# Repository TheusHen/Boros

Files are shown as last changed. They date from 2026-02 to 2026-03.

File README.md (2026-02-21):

# Boros Rocket

*Amateur rocket created by an 15 year old teenager.*

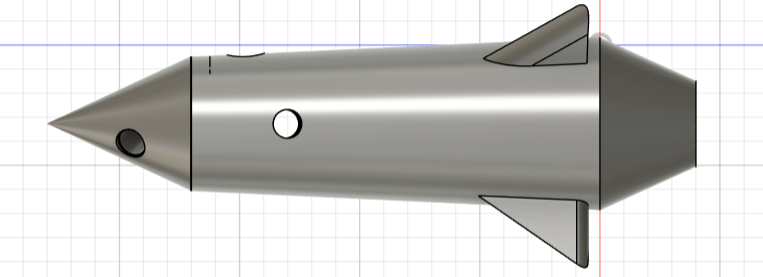
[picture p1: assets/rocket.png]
Boros Rocket


This repository contains the current **Beta** state of the Boros rocket avionics stack.  
The project has already passed **Pre-Alpha** and **Alpha** stages and is now focused on stabilizing hardware-software integration with the **Plate PCB version**.

## Current Focus

- Firmware flight logging and fault handling (`firmware/`)
- Physics-based flight simulation and Monte Carlo (`sim/flight/`)
- PCB design and manufacturing outputs (`PCB/plate_version/`)
- CI pipeline with firmware build, simulation, and reporting (`.github/workflows/ci.yml`)

## Hardware Direction (Plate Version)

We are using the **Plate PCB** approach (not the Coin version), currently at **V4 (2 layers)**.

### PCB and 3D previews

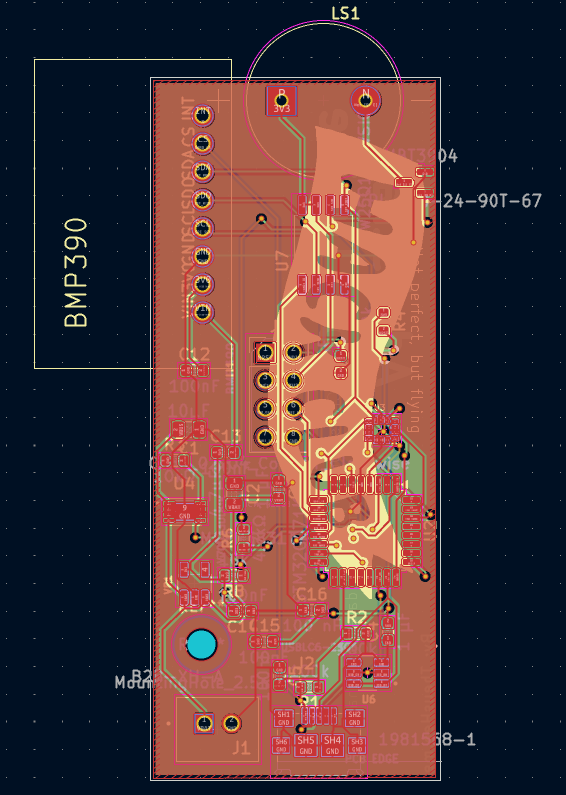
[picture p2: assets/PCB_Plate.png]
PCB Plate

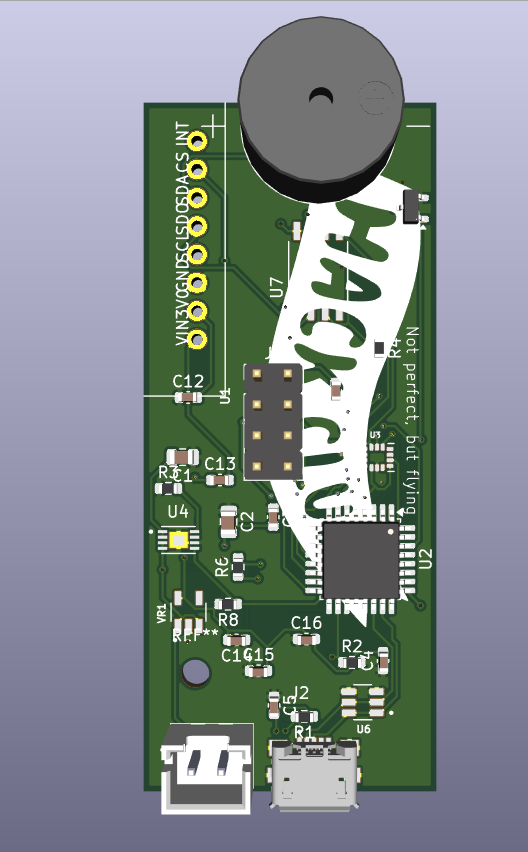
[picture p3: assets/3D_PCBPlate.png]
3D Plate Integration


### PCB iteration history (Plate)

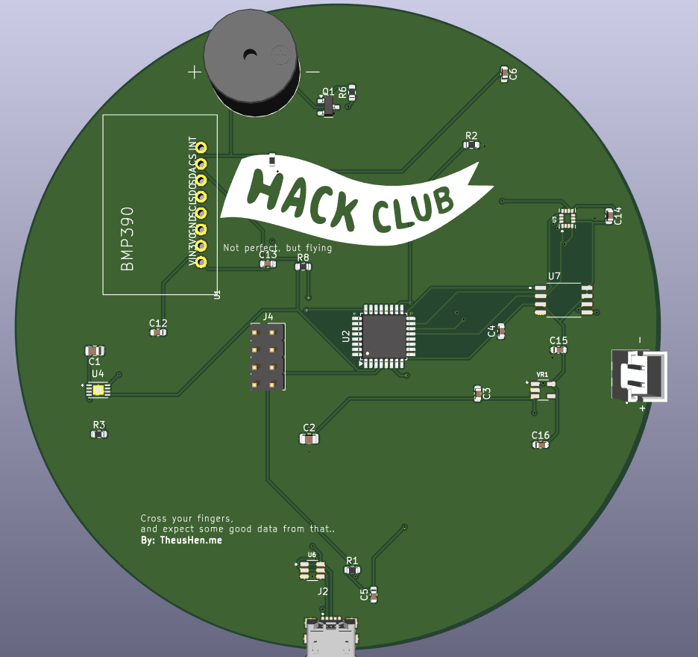
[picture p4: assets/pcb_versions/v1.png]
PCB Version v1

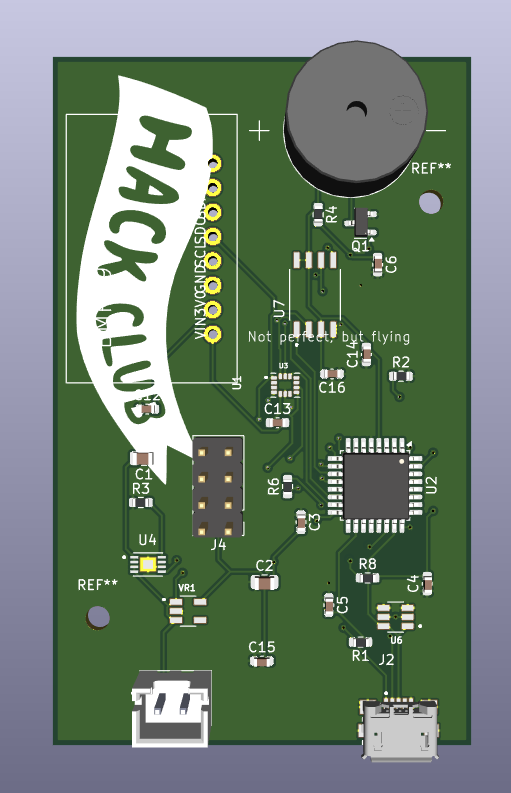
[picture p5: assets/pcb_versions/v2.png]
PCB Version v2

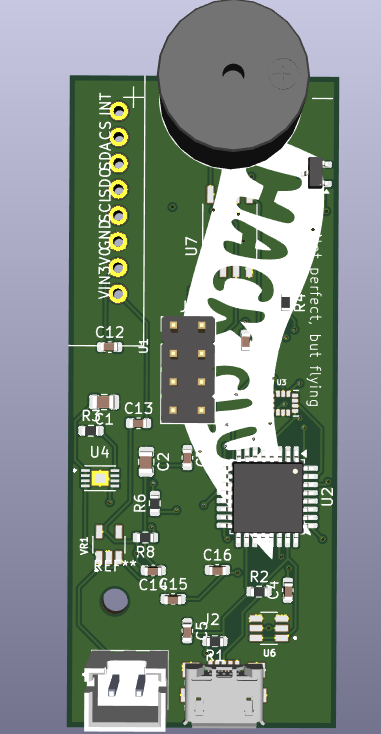
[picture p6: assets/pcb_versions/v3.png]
PCB Version v3

PCB Version v4

## Mass Budget Baseline (Plate)

The mass budget tool is used to estimate liftoff mass from:

- Rocket 3D model volume
- Motor mass: **24.1 g**
- PCB plate geometry: **25 mm x 62 mm**, **2 copper layers**
- Motor limit check: **113 g max liftoff mass**

Run:

```bash
make python-mass-budget
```

Outputs:

- `sim/flight/out/mass_budget.json`
- `sim/flight/out/mass_budget.md`

## Simulation Workflow

The Python simulation now consumes the mass budget output and uses the suggested total mass automatically.

Run:

```bash
make python-sim
```

This generates:

- Flight timeseries and summary
- Monte Carlo summary
- Firmware-like sensor log for playback/testing

## Quick Commands

```bash
make firmware
make python-check
make python-sim
make python-firmware-playback
make python-mass-budget
```

## Notes

- The repository includes both firmware and simulation assets to support rapid iteration.
- CI publishes simulation and firmware validation artifacts for each run.

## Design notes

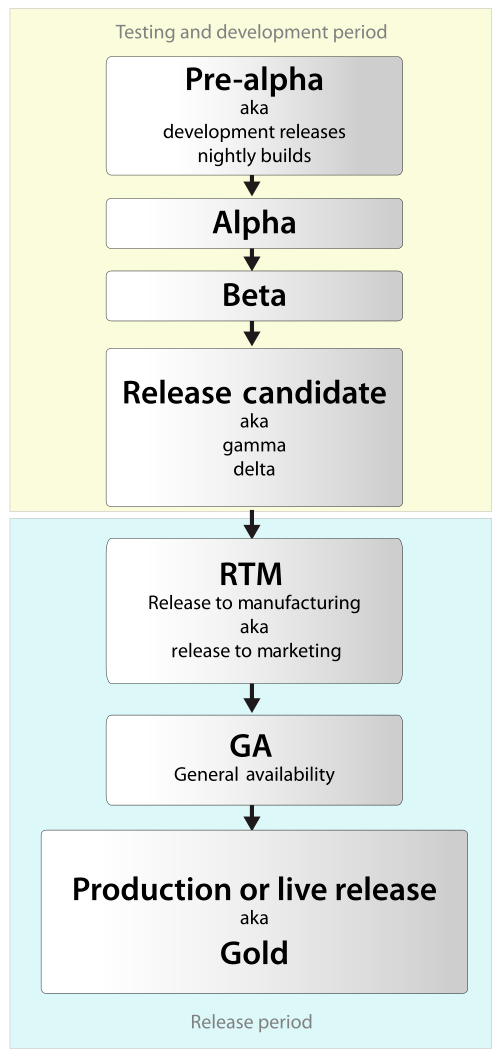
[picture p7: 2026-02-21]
.github/readme/assets/release-cycle.png

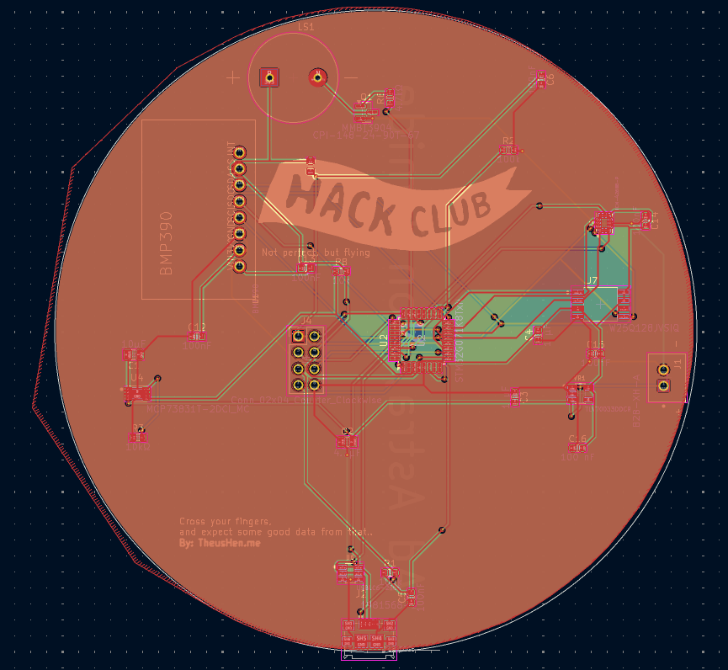
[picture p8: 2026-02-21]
assets/PCB_Coin.png

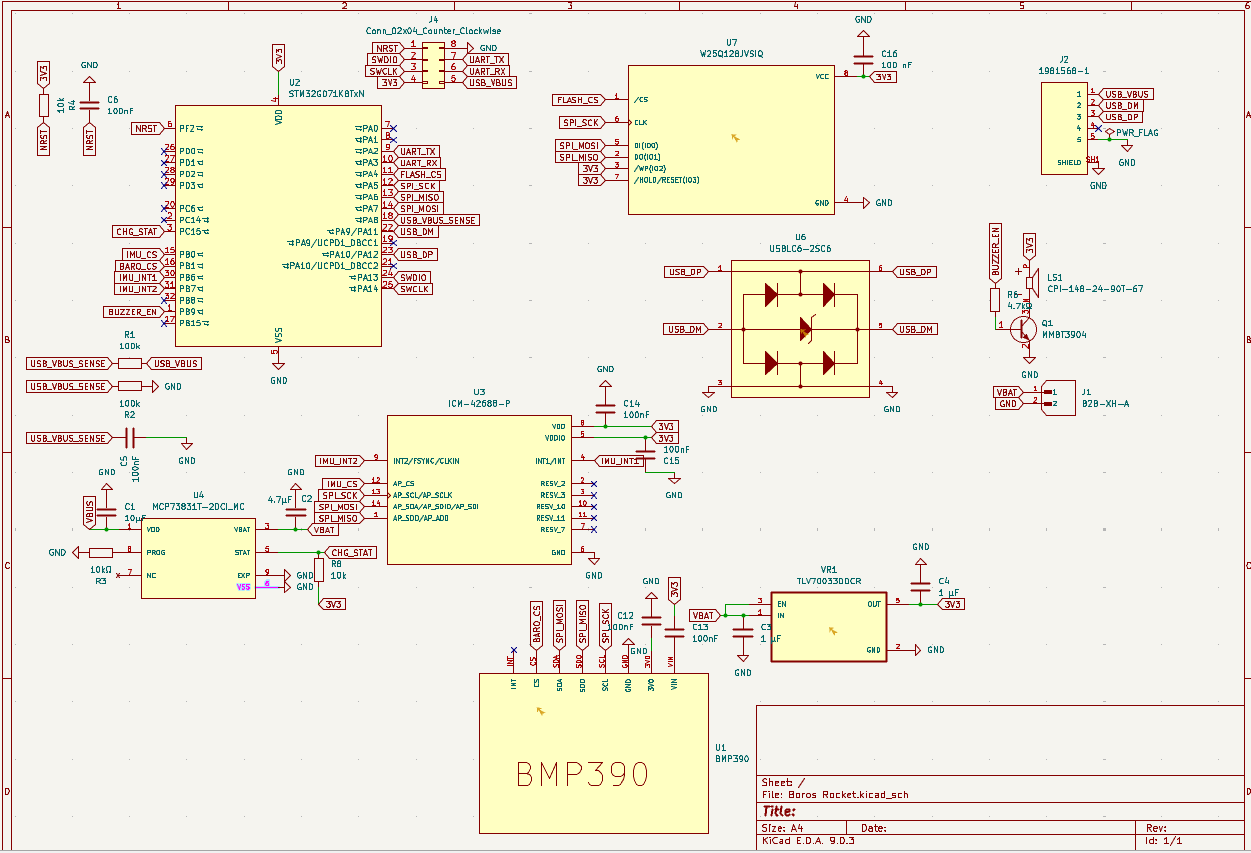
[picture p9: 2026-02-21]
assets/SCH.png

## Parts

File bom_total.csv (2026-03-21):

Category | Item | Mfr. # | Qty | Unit Price (USD) | Total (USD) | Notes
Mouser - Components | Multilayer Ceramic Capacitors - 100nF | 06031C104MAT2A | 6 | $0.37 | $2.22
Mouser - Components | Multilayer Ceramic Capacitors - 1uF 10V X7R | CM105X7R105K10AT | 4 | $0.18 | $0.72 | Factory Special Order
Mouser - Components | Multilayer Ceramic Capacitors - 10uF X7R | 0805X7R106KT1AT | 4 | $0.92 | $3.68
Mouser - Components | Multilayer Ceramic Capacitors - 4.7uF 6.3V | 08056D475MAT2A | 4 | $0.40 | $1.60
Mouser - Components | Thick Film Resistor 910K | CRCW0603910KFKEAHP | 3 | $0.19 | $0.57
Mouser - Components | Thick Film Resistor 100K | RCA0603100KFKEC | 4 | $0.11 | $0.44 | New At Mouser
Mouser - Components | Thick Film Resistor 4.7K 5% | CRCW06034K70JNEA | 3 | $0.10 | $0.30
Mouser - Components | Barometric Pressure Sensor | BMP390 | 3 | $3.08 | $9.24
Mouser - Components | ARM Cortex-M0+ MCU | STM32L081KZT6 | 2 | $4.48 | $8.96
Mouser - Components | 6-Axis IMU | ICM-42688-P | 2 | $5.53 | $11.06
Mouser - Components | Battery Charge Management Controller | MCP73831T-2DCI/MC | 2 | $0.79 | $1.58
Mouser - Components | ESD Protection Diode Low Cap | USBLC6-2SC6 | 3 | $0.36 | $1.08
Mouser - Components | Piezo Buzzer 13.9mm 24V 90dB | CPI-148-24-90T-67 | 2 | $1.82 | $3.64
Mouser - Components | NPN BJT SOT-23 40V 200mA | MMBT3904 | 4 | $0.12 | $0.48
Mouser - Components | LDO Regulator 200mA Low IQ | TLV70033DDCR | 3 | $0.23 | $0.69
Mouser - Components | XH Header 2-pin Top Entry | B2B-XH-A(LF)(SN) | 2 | $0.10 | $0.20 | New At Mouser
Mouser - Components | Micro USB Type B Receptacle | 1981568-1 | 2 | $2.18 | $4.36
Mouser - Subtotal | Components only | — | — | — | $50.82
Mouser - Shipping | Standard | — | — | — | $35.00
Mouser - Backorder Shipping | Standard | — | — | — | $35.00
Mouser - TOTAL | — | — | — | — | $120.82
PCB - Fabrication | PCB Calculated Price | — | 1 | $2.10 | $2.10 | Additional charges may apply for special cases
PCB - Shipping | Global Standard Direct Line | — | — | — | $3.12 | 8-13 business days
PCB - TOTAL | — | — | — | — | $5.22
STM32 - MCU | STM32G071K8TxN LQFP-32 | STM32G071K8T6N | 2 | ~$3.00 | ~$6.00 | ESTIMATED - No stock at authorized distributors (21-Mar-26). Price based on ST suggested resale range for STM32G071 family in small qty.
STM32 - TOTAL | — | — | — | — | ~$6.00 | ESTIMATED
GRAND TOTAL | Mouser + PCB + STM32 (est.) | — | — | — | ~$132.04 | STM32 portion is estimated — final value may vary

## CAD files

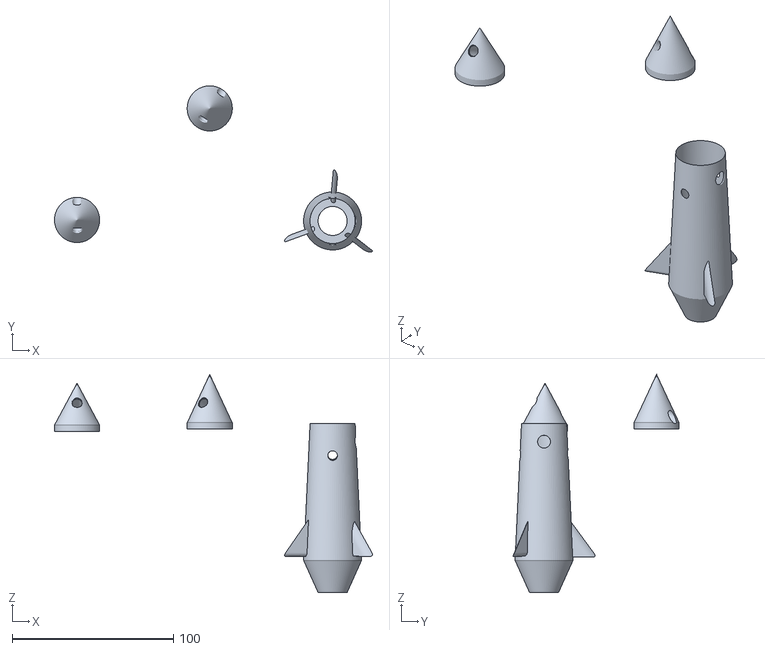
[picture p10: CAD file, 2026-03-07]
3d/BorosRocket_ToPrint.stl
197.4 x 103.2 x 135.4

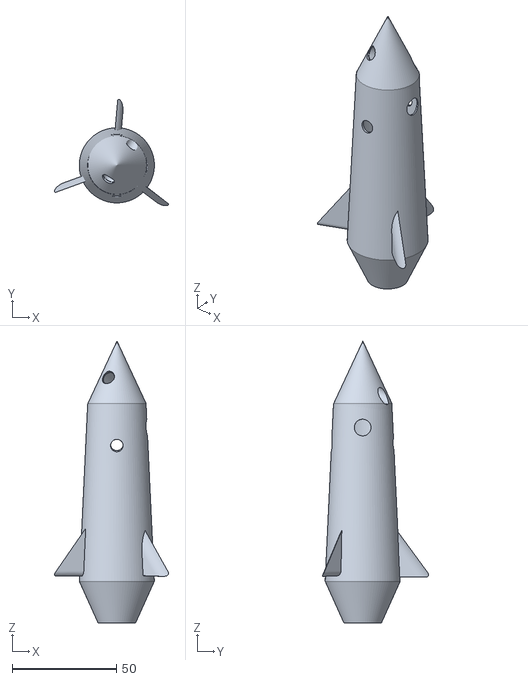
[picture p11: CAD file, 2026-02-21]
3d/BorosRocket.stl
54.6 x 51.0 x 135.1

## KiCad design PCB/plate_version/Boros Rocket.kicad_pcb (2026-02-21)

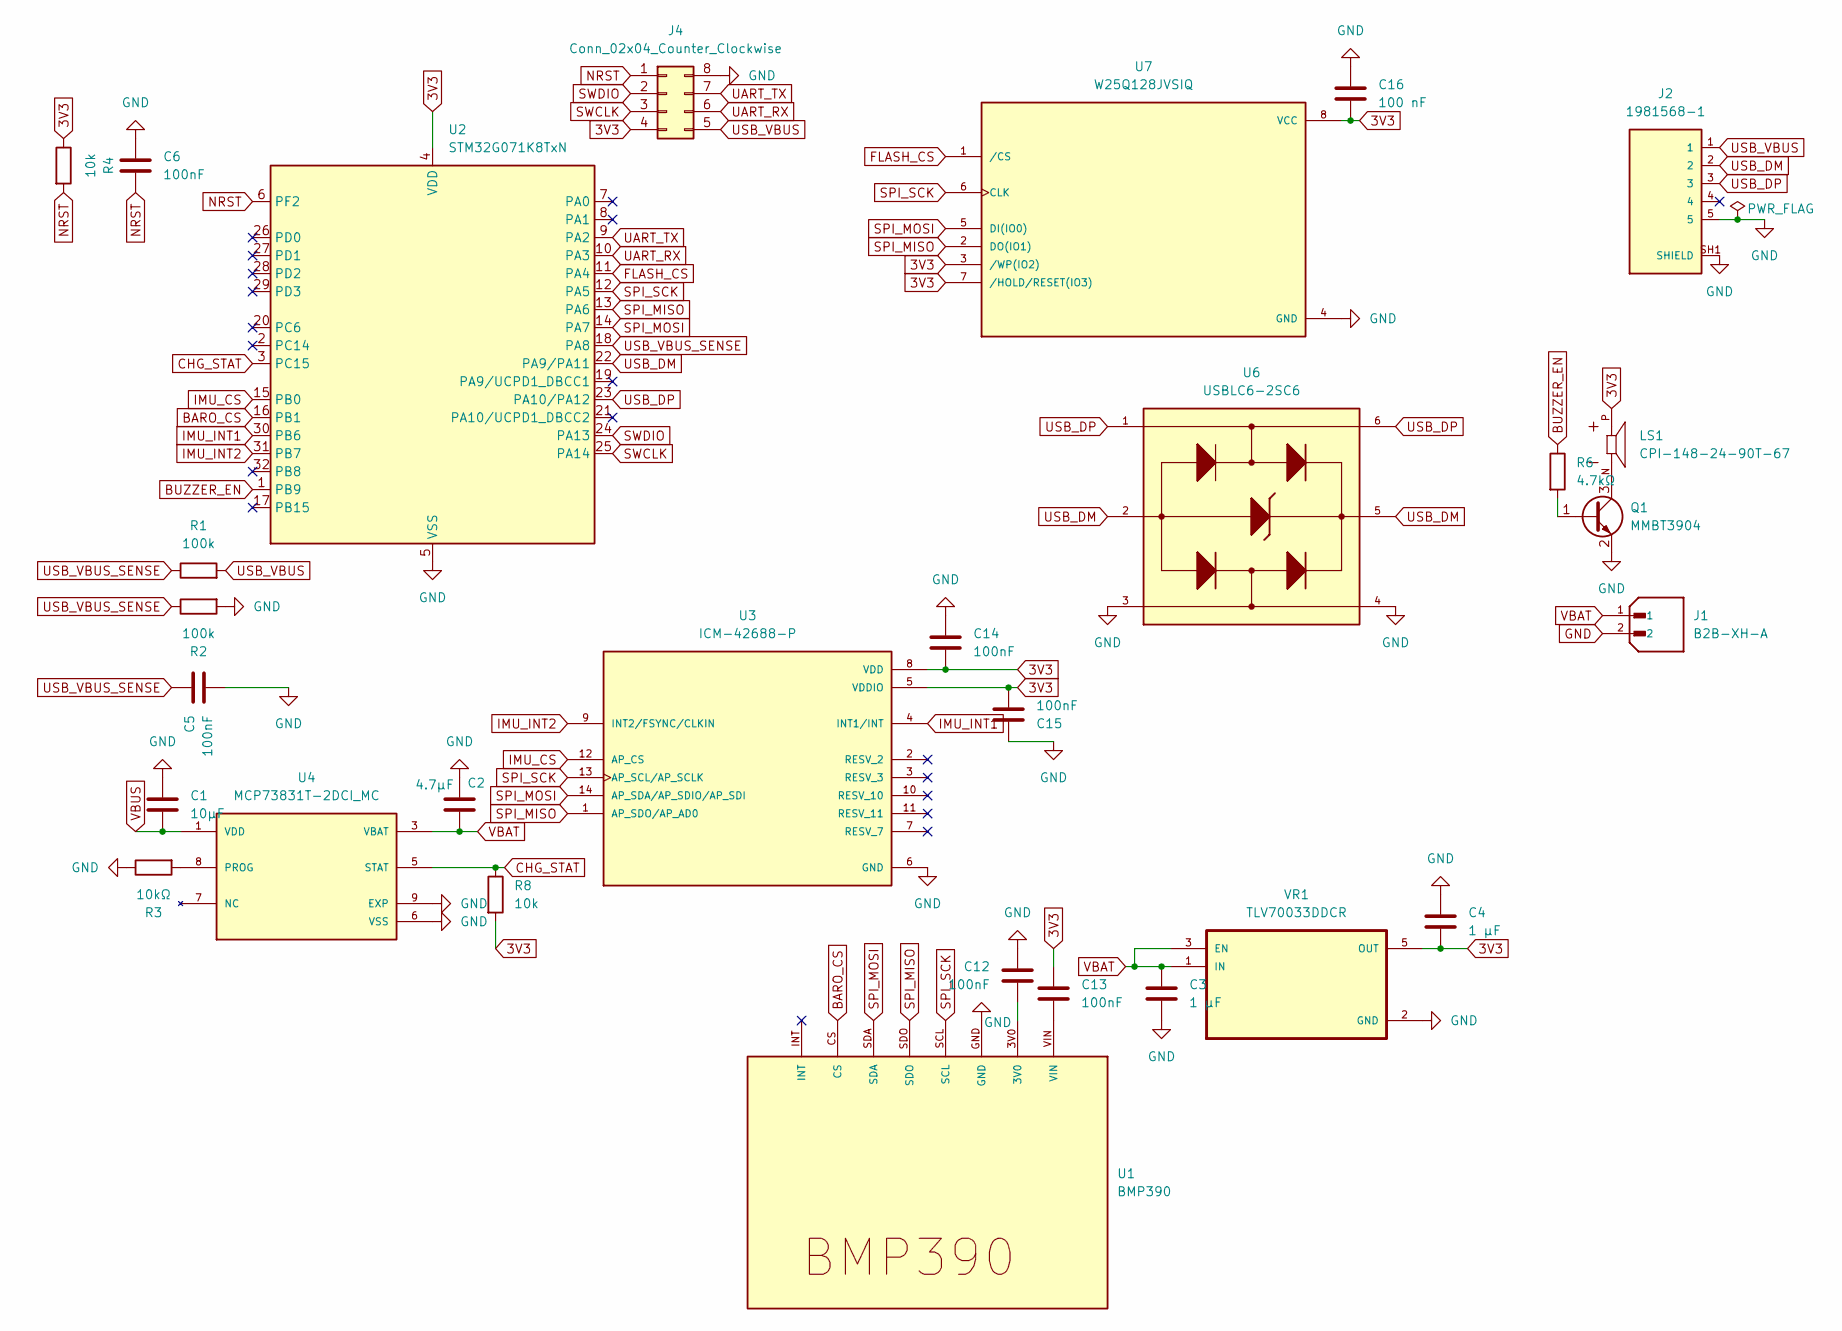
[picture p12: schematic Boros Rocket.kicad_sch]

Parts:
C1: 10µF; C_0805_2012Metric
C2: 4.7µF; C_0805_2012Metric
C3, C4: 1 µF; C_0603_1608Metric
C5, C6, C12, C13, C14, C15: 100nF; C_0603_1608Metric
C16: 100 nF; C_0603_1608Metric
J1: B2B-XH-A; JST_B2B-XH-A; PARTREV N/A
J2: 1981568-1; TE_1981568-1; PARTREV E3
J4: Conn_02x04_Counter_Clockwise; PinHeader_2x04_P2.54mm_Vertical
LS1: CPI-148-24-90T-67; XDCR_CPI-148-24-90T-67; PARTREV 1
Q1: MMBT3904; SOT-23
R1, R2: 100k; R_0603_1608Metric
R3: 10kΩ; R_0603_1608Metric
R4, R8: 10k; R_0603_1608Metric
R6: 4.7kΩ; R_0603_1608Metric
U1: BMP390
U2: STM32G071K8TxN; LQFP-32_7x7mm_P0.8mm
U3: ICM-42688-P; PQFN50P300X250X97-14N; PARTREV 1.2
U4: MCP73831T-2DCI_MC; SON50P200X300X100-9N; PARTREV H
U6: USBLC6-2SC6; SOT95P280X145-6N
U7: W25Q128JVSIQ; SOIC127P790X216-8N; PARTREV I
VR1: TLV70033DDCR; SOT95P280X110-5N

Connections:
3V3: C4.2, C13.1, C14.2, C15.2, C16.2, J4.4, LS1.P, R4.1, R8.2, U2.4 (VDD), U3.5 (VDDIO), U3.8 (VDD), U7.3 (/WP(IO2)), U7.7 (/HOLD/RESET(IO3)), U7.8 (VCC), VR1.5 (OUT)
BARO_CS: U1.CS, U2.16 (PB1)
BUZZER_EN: R6.1, U2.1 (PB9)
CHG_STAT: R8.1, U2.3 (PC15), U4.5 (STAT)
FLASH_CS: U2.11 (PA4), U7.1 (/CS)
GND: C1.1, C2.1, C3.1, C4.1, C5.1, C6.2, C12.1, C14.1, C15.1, C16.1, J1.2, J2.5, J2.SH1 (SHIELD), J2.SH2 (SHIELD), J2.SH3 (SHIELD), J2.SH4 (SHIELD), J2.SH5 (SHIELD), J2.SH6 (SHIELD), J4.8, Q1.2 (E), R2.2, R3.1, U1.GND, U2.5 (VSS), U3.6 (GND), U4.6 (VSS), U4.9 (EXP), U6.3, U6.4, U7.4 (GND), VR1.2 (GND)
IMU_CS: U2.15 (PB0), U3.12 (AP_CS)
IMU_INT1: U2.30 (PB6), U3.4 (INT1/INT)
IMU_INT2: U2.31 (PB7), U3.9 (INT2/FSYNC/CLKIN)
NRST: C6.1, J4.1, R4.2, U2.6 (PF2)
unnamed: C12.2, U1.3V0
unnamed: C13.2, U1.VIN
unnamed: Q1.1 (B), R6.2
unnamed: LS1.N, Q1.3 (C)
unnamed: R3.2, U4.8 (PROG)
SPI_MISO: U1.SDO, U2.13 (PA6), U3.1 (AP_SDO/AP_AD0), U7.2 (DO(IO1))
SPI_MOSI: U1.SDA, U2.14 (PA7), U3.14 (AP_SDA/AP_SDIO/AP_SDI), U7.5 (DI(IO0))
SPI_SCK: U1.SCL, U2.12 (PA5), U3.13 (AP_SCL/AP_SCLK), U7.6 (CLK)
SWCLK: J4.3, U2.25 (PA14)
SWDIO: J4.2, U2.24 (PA13)
UART_RX: J4.6, U2.10 (PA3)
UART_TX: J4.7, U2.9 (PA2)
USB_DM: J2.2, U2.22 (PA9/PA11), U6.2, U6.5
USB_DP: J2.3, U2.23 (PA10/PA12), U6.1, U6.6
USB_VBUS: J2.1, J4.5, R1.2
USB_VBUS_SENSE: C5.2, R1.1, R2.1, U2.18 (PA8)
VBAT: C2.2, C3.2, J1.1, U4.3 (VBAT), U4.4 (VBAT), VR1.1 (IN), VR1.3 (EN)
VBUS: C1.2, U4.1 (VDD), U4.2 (VDD)

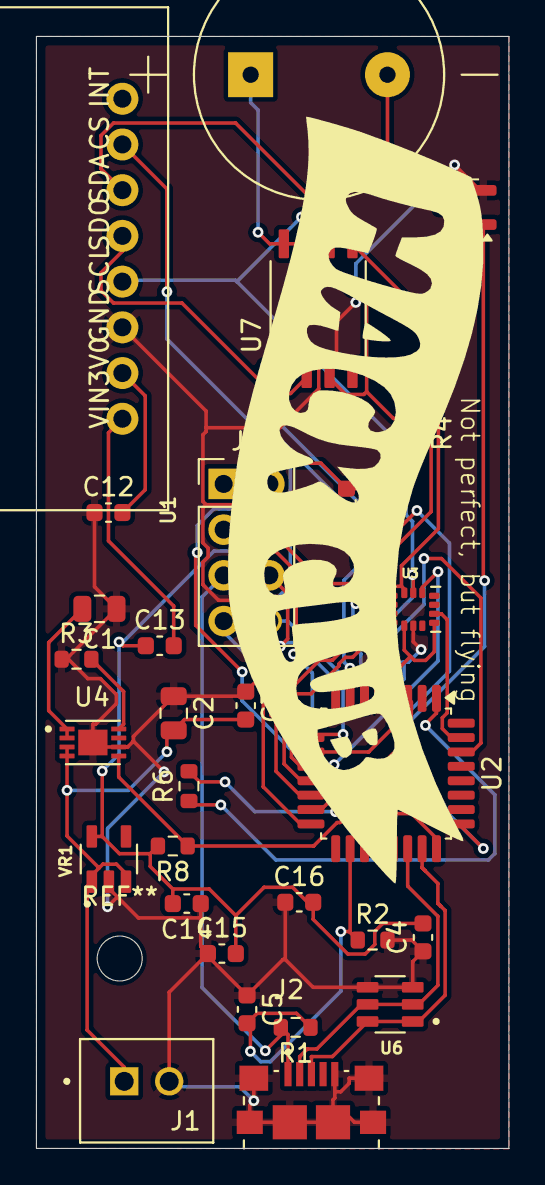
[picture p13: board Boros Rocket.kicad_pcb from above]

Board: 2 copper layers, 26.3 x 61.8 mm, 29 parts (0 on the bottom side), 28 nets.

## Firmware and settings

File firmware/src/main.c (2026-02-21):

#include <math.h>
#include <stdint.h>
#include <stdio.h>

#include "bmp390.h"
#include "fault.h"
#include "flash_w25q.h"
#include "flight_fsm.h"
#include "gpio.h"
#include "icm42688.h"
#include "log.h"
#include "spi.h"
#include "systick.h"
#include "uart.h"

#define CPU_HZ 16000000u

#define SAMPLE_PERIOD_MS   10u
#define IMU_CAL_SAMPLES    256u
#define BARO_BASE_SAMPLES  128u
#define SENSOR_RETRY_MS    500u
#define LOG_FLUSH_MS       250u
#define HEALTH_REPORT_MS  1000u
#define WDT_TIMEOUT_MS   30000u

#define VBAT_UNKNOWN_MV (-1)

#define BMP_MIN_VALID_PA     20000
#define BMP_MAX_VALID_PA    120000
#define TEMP_MIN_VALID_CENTI -5000
#define TEMP_MAX_VALID_CENTI 10000

/* ICM-42688 configured to +/-16g and +/-2000dps. */
#define ICM_ACC_LSB_PER_G        2048
#define ICM_GYR_DPS_X10_DIVISOR  164 /* raw * 100 / 164 = dps*10 */

typedef struct {
  int64_t sum_ax, sum_ay, sum_az;
  int64_t sum_gx, sum_gy, sum_gz;
  uint16_t count;
  int16_t ax_bias, ay_bias, az_bias;
  int16_t gx_bias, gy_bias, gz_bias;
  uint8_t done;
} imu_cal_t;

static void beep(int n) {
  for (int i = 0; i < n; i++) {
    buzzer_set(1);
    for (volatile int d = 0; d < 70000; d++) { }
    buzzer_set(0);
    for (volatile int d = 0; d < 70000; d++) { }
  }
}

static int16_t sat_i16(int32_t v) {
  if (v > 32767) return 32767;
  if (v < -32768) return -32768;
  return (int16_t)v;
}

static uint32_t isqrt_u64(uint64_t x) {
  uint64_t res = 0;
  uint64_t bit = (uint64_t)1 << 62;
  while (bit > x) bit >>= 2;

  while (bit != 0) {
    if (x >= (res + bit)) {
      x -= (res + bit);
      res = (res >> 1) + bit;
    } else {
      res >>= 1;
    }
    bit >>= 2;
  }

  return (uint32_t)res;
}

static int bmp_sample_is_valid(const bmp390_sample_t* s) {
  if (!s) return 0;
  if ((s->press_pa < BMP_MIN_VALID_PA) || (s->press_pa > BMP_MAX_VALID_PA)) return 0;
  if ((s->temp_centi < TEMP_MIN_VALID_CENTI) || (s->temp_centi > TEMP_MAX_VALID_CENTI)) return 0;
  return 1;
}

static int32_t pressure_to_altitude_cm(int32_t pressure_pa, int32_t base_pa) {
  if ((pressure_pa <= 0) || (base_pa <= 0)) return 0;

  float ratio = (float)pressure_pa / (float)base_pa;
  if (ratio < 0.05f) ratio = 0.05f;
  if (ratio > 1.2f) ratio = 1.2f;

  /* ISA troposphere approximation. */
  float alt_m = 44330.0f * (1.0f - powf(ratio, 0.19029495f));
  if (alt_m < 0.0f) alt_m = 0.0f;
  if (alt_m > 100000.0f) alt_m = 100000.0f;

  return (int32_t)(alt_m * 100.0f + 0.5f);
}

static void imu_cal_feed(imu_cal_t* c, const int16_t acc[3], const int16_t gyr[3]) {
  if (c->done) return;

  c->sum_ax += acc[0];
  c->sum_ay += acc[1];
  c->sum_az += acc[2];
  c->sum_gx += gyr[0];
  c->sum_gy += gyr[1];
  c->sum_gz += gyr[2];
  c->count++;

  if (c->count < IMU_CAL_SAMPLES) return;

  int32_t ax_m = (int32_t)(c->sum_ax / c->count);
  int32_t ay_m = (int32_t)(c->sum_ay / c->count);
  int32_t az_m = (int32_t)(c->sum_az / c->count);

  c->gx_bias = sat_i16((int32_t)(c->sum_gx / c->count));
  c->gy_bias = sat_i16((int32_t)(c->sum_gy / c->count));
  c->gz_bias = sat_i16((int32_t)(c->sum_gz / c->count));

  /* Remove static accel bias while preserving ~1g along measured direction. */
  uint64_t mag2 = (uint64_t)((int64_t)ax_m * ax_m + (int64_t)ay_m * ay_m + (int64_t)az_m * az_m);
  uint32_t mag = isqrt_u64(mag2);
  if (mag > 0) {
    c->ax_bias = sat_i16(ax_m - (int32_t)(((int64_t)ax_m * ICM_ACC_LSB_PER_G) / mag));
    c->ay_bias = sat_i16(ay_m - (int32_t)(((int64_t)ay_m * ICM_ACC_LSB_PER_G) / mag));
    c->az_bias = sat_i16(az_m - (int32_t)(((int64_t)az_m * ICM_ACC_LSB_PER_G) / mag));
  } else {
    c->ax_bias = 0;
    c->ay_bias = 0;
    c->az_bias = 0;
  }

  c->done = 1;
}

int main(void) {
  fault_boot_init();
  uint32_t reset_cause = fault_get_reset_cause();

  gpio_init_all();
  uart2_init(CPU_HZ, 115200);
  spi1_init();
  systick_init_1ms(CPU_HZ);
  fault_watchdog_init(WDT_TIMEOUT_MS);

  uart2_puts("BOOT\r\n");
  if (fault_had_hardfault()) {
    uart2_puts("PREV HARDFAULT\r\n");
  }
  {
    char rst_line[48];
    int rn = snprintf(rst_line, sizeof(rst_line), "RESET CAUSE 0x%02lX\r\n", (unsigned long)reset_cause);
    if (rn > 0) {
      uart2_puts(rst_line);
    }
  }
  beep(2);

  int log_ok = (log_init() == 0);
  uint32_t flash_id = 0;
  int flash_id_ok = log_ok && (w25q_read_jedec_id(&flash_id) == 0);
  if (flash_id_ok) {
    char id_line[40];
    int id_n = snprintf(id_line, sizeof(id_line), "FLASH ID 0x%06lX\r\n", (unsigned long)flash_id);
    if (id_n > 0) {
      uart2_puts(id_line);
    }
  } else {
    uart2_puts("FLASH ID FAIL\r\n");
  }
  uart2_puts(log_ok ? "LOG FLASH\r\n" : "LOG RAM FALLBACK\r\n");

  int bmp_ready = (bmp390_init() == 0);
  int imu_ready = (icm42688_init() == 0);
  uart2_puts(bmp_ready ? "BMP OK\r\n" : "BMP FAIL\r\n");
  uart2_puts(imu_ready ? "IMU OK\r\n" : "IMU FAIL\r\n");
  uart2_puts("SYS READY\r\n");

  imu_cal_t imu_cal = {0};
  int imu_cal_announced = 0;

  int64_t baro_sum_pa = 0;
  uint16_t baro_count = 0;
  int32_t baro_base_pa = 101325;
  int baro_base_ready = 0;

  bmp390_sample_t bmp_last = {0};
  bmp_last.press_pa = baro_base_pa;
  bmp_last.temp_centi = 2500;
  int bmp_have_last = 0;
  uint16_t bmp_stale_count = 0;

  int16_t acc_last[3] = {0, 0, ICM_ACC_LSB_PER_G};
  int16_t gyr_last[3] = {0, 0, 0};
  int imu_have_last = 0;
  uint16_t imu_stale_count = 0;

  int32_t alt_last_cm = 0;
  uint32_t alt_last_ms = 0;
  int32_t vz_lp_cms = 0;

  flight_fsm_t flight_fsm;
  flight_events_t flight_events = {0};
  flight_fsm_init(&flight_fsm, 0);

  uint32_t last_sample = 0;
  uint32_t last_retry = 0;
  uint32_t last_flush = 0;
  uint32_t last_health = 0;

  while (1) {
    fault_watchdog_kick();

    int c = uart2_getc_nonblock();
    if ((c == 'D') || (c == 'd')) {
      beep(1);
      fault_watchdog_kick();
      log_dump_uart();
      fault_watchdog_kick();
      beep(3);
    } else if ((c == 'F') || (c == 'f')) {
      log_flush();
      uart2_puts("LOG FLUSH\r\n");
    }

    uint32_t now = millis();
    if ((now - last_sample) < SAMPLE_PERIOD_MS) {
      continue;
    }
    last_sample = now;

    if (((!bmp_ready) || (!imu_ready)) && ((now - last_retry) >= SENSOR_RETRY_MS)) {
      last_retry = now;
      if (!bmp_ready) bmp_ready = (bmp390_init() == 0);
      if (!imu_ready) imu_ready = (icm42688_init() == 0);
    }

    bmp390_sample_t bmp = bmp_last;
    int bmp_ok = 0;
    if (bmp_ready) {
      if ((bmp390_read_sample(&bmp) == 0) && bmp_sample_is_valid(&bmp)) {
        bmp_ok = 1;
        bmp_last = bmp;
        bmp_have_last = 1;
        bmp_stale_count = 0;
      } else {
        bmp_ready = 0;
      }
    }
    if (!bmp_ok) {
      if (bmp_have_last) {
        bmp = bmp_last;
      } else {
        bmp.press_pa = baro_base_pa;
        bmp.temp_centi = 0;
      }
      if (bmp_stale_count < 0xFFFFu) bmp_stale_count++;
    }

    int16_t acc_raw[3] = {0, 0, ICM_ACC_LSB_PER_G};
    int16_t gyr_raw[3] = {0, 0, 0};
    int imu_ok = 0;
    if (imu_ready) {
      if (icm42688_read6(acc_raw, gyr_raw) == 0) {
        imu_ok = 1;
        for (int i = 0; i < 3; ++i) {
          acc_last[i] = acc_raw[i];
          gyr_last[i] = gyr_raw[i];
        }
        imu_have_last = 1;
        imu_stale_count = 0;
      } else {
        imu_ready = 0;
      }
    }
    if (!imu_ok) {
      if (imu_have_last) {
        for (int i = 0; i < 3; ++i) {
          acc_raw[i] = acc_last[i];
          gyr_raw[i] = gyr_last[i];
        }
      }
      if (imu_stale_count < 0xFFFFu) imu_stale_count++;
    }

    if (imu_ok) {
      imu_cal_feed(&imu_cal, acc_raw, gyr_raw);
      if (imu_cal.done && !imu_cal_announced) {
        imu_cal_announced = 1;
        uart2_puts("IMU CAL OK\r\n");
      }
    }

    if (bmp_ok && !baro_base_ready) {
      baro_sum_pa += bmp.press_pa;
      baro_count++;
      if (baro_count >= BARO_BASE_SAMPLES) {
        baro_base_pa = (int32_t)(baro_sum_pa / baro_count);
        if (baro_base_pa < BMP_MIN_VALID_PA || baro_base_pa > BMP_MAX_VALID_PA) {
          baro_base_pa = 101325;
        }
        baro_base_ready = 1;
        uart2_puts("BARO BASE OK\r\n");
      }
    }

    int32_t ax_corr = acc_raw[0] - imu_cal.ax_bias;
    int32_t ay_corr = acc_raw[1] - imu_cal.ay_bias;
    int32_t az_corr = acc_raw[2] - imu_cal.az_bias;

    int32_t gx_corr = gyr_raw[0] - imu_cal.gx_bias;
    int32_t gy_corr = gyr_raw[1] - imu_cal.gy_bias;
    int32_t gz_corr = gyr_raw[2] - imu_cal.gz_bias;

    int16_t ax_mg = sat_i16((ax_corr * 1000) / ICM_ACC_LSB_PER_G);
    int16_t ay_mg = sat_i16((ay_corr * 1000) / ICM_ACC_LSB_PER_G);
    int16_t az_mg = sat_i16((az_corr * 1000) / ICM_ACC_LSB_PER_G);

    int16_t gx_dps_x10 = sat_i16((gx_corr * 100) / ICM_GYR_DPS_X10_DIVISOR);
    int16_t gy_dps_x10 = sat_i16((gy_corr * 100) / ICM_GYR_DPS_X10_DIVISOR);
    int16_t gz_dps_x10 = sat_i16((gz_corr * 100) / ICM_GYR_DPS_X10_DIVISOR);

    int32_t pressure_pa = bmp.press_pa;
    int16_t temp_centi = bmp.temp_centi;
    int32_t altitude_cm = 0;
    if (baro_base_ready) {
      altitude_cm = pressure_to_altitude_cm(pressure_pa, baro_base_pa);
    }

    if (baro_base_ready) {
      if (alt_last_ms != 0u && now > alt_last_ms) {
        uint32_t dt_ms = now - alt_last_ms;
        int32_t vz_inst = (int32_t)(((int64_t)(altitude_cm - alt_last_cm) * 1000LL) / (int64_t)dt_ms);
        vz_lp_cms = ((vz_lp_cms * 7) + vz_inst) / 8;
      }
      alt_last_ms = now;
      alt_last_cm = altitude_cm;
    } else {
      vz_lp_cms = (vz_lp_cms * 7) / 8;
    }
    int16_t vz_cms = sat_i16(vz_lp_cms);

    int arm_ok = baro_base_ready && imu_cal.done && !usb_vbus_sense_read();
    int sensors_ok = (bmp_ok || bmp_have_last) && (imu_ok || imu_have_last);
    flight_fsm_step(&flight_fsm, now, altitude_cm, az_mg, vz_cms, sensors_ok, arm_ok, &flight_events);
    flight_state_t flight_state = flight_fsm_state(&flight_fsm);

    uint32_t flags = 0;
    if (bmp_ok) flags |= LOG_FLAG_BMP_OK;
    if (imu_ok) flags |= LOG_FLAG_IMU_OK;
    if (!bmp_ok) flags |= LOG_FLAG_BMP_STALE;
    if (!imu_ok) flags |= LOG_FLAG_IMU_STALE;
    if (imu_cal.done) flags |= LOG_FLAG_IMU_CAL_DONE;
    if (baro_base_ready) flags |= LOG_FLAG_BARO_BASE_OK;
    if (usb_vbus_sense_read()) flags |= LOG_FLAG_USB_VBUS;
    if (chg_stat_read()) flags |= LOG_FLAG_CHG_STAT;
    if (imu_int1_read()) flags |= LOG_FLAG_IMU_INT1;
    if (imu_int2_read()) flags |= LOG_FLAG_IMU_INT2;
    if (log_is_flash_enabled()) {
      flags |= LOG_FLAG_FLASH_OK;
    } else {
      flags |= LOG_FLAG_FLASH_FALLBK;
    }
    if (log_dropped_records() != 0u) {
      flags |= LOG_FLAG_LOG_DROPPED;
    }
    if (flight_events.launch) flags |= LOG_FLAG_EVT_LAUNCH;
    if (flight_events.apogee) flags |= LOG_FLAG_EVT_APOGEE;
    if (flight_events.landed) flags |= LOG_FLAG_EVT_LANDED;
    if (flight_state == FLIGHT_STATE_ARMED) flags |= LOG_FLAG_ARMED;
    if (flight_state == FLIGHT_STATE_FAULT) flags |= LOG_FLAG_FLIGHT_FAULT;
    if (reset_cause & RESET_CAUSE_WDT) flags |= LOG_FLAG_RST_WDT;
    if (reset_cause & RESET_CAUSE_BOR) flags |= LOG_FLAG_RST_BOR;
    if (reset_cause & RESET_CAUSE_PIN) flags |= LOG_FLAG_RST_PIN;
    if (reset_cause & RESET_CAUSE_SOFT) flags |= LOG_FLAG_RST_SOFT;
    if (reset_cause & RESET_CAUSE_HARDFAULT) flags |= LOG_FLAG_RST_HFAULT;

    log_rec_t rec = {0};
    rec.ms = now;
    rec.pressure_pa = pressure_pa;
    rec.altitude_cm = altitude_cm;
    rec.temp_centi = temp_centi;
    rec.ax_mg = ax_mg;
    rec.ay_mg = ay_mg;
    rec.az_mg = az_mg;
    rec.gx_dps_x10 = gx_dps_x10;
    rec.gy_dps_x10 = gy_dps_x10;
    rec.gz_dps_x10 = gz_dps_x10;
    rec.vz_cms = vz_cms;
    rec.vbat_mv = VBAT_UNKNOWN_MV;
    rec.bmp_stale = bmp_stale_count;
    rec.imu_stale = imu_stale_count;
    rec.flight_state = (uint8_t)flight_state;
    rec.reset_cause = (uint8_t)(reset_cause & 0xFFu);
    rec.flags = flags;

    log_append(&rec);

    if ((now - last_flush) >= LOG_FLUSH_MS) {
      last_flush = now;
      log_flush();
    }

    if ((now - last_health) >= HEALTH_REPORT_MS) {
      last_health = now;
      char line[180];
      int n = snprintf(line, sizeof(line),
                       "STAT t=%lu st=%u bmp=%d imu=%d bStale=%u iStale=%u flash=%d drop=%lu\r\n",
                       (unsigned long)now,
                       (unsigned)flight_state,
                       bmp_ready ? 1 : 0,
                       imu_ready ? 1 : 0,
                       (unsigned)bmp_stale_count,
                       (unsigned)imu_stale_count,
                       log_is_flash_enabled(),
                       (unsigned long)log_dropped_records());
      if (n > 0) {
        uart2_puts(line);
      }
    }
  }
}

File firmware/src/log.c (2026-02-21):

#include "log.h"

#include <stdio.h>
#include <string.h>

#include "flash_w25q.h"
#include "fault.h"
#include "uart.h"

#define LOG_BASE        0x000000u
#define LOG_SIZE        (16u * 1024u * 1024u) /* W25Q128 = 16MB */
#define LOG_SECTOR_SZ   4096u
#define LOG_PAGE_MAX    256u
#define LOG_RAM_RECS    256u

#define LOG_PKT_KEY     0xA1u
#define LOG_PKT_DELTA   0xA2u
#define LOG_KEY_INTERVAL 32u
#define LOG_MAX_PAYLOAD 220u
#define LOG_MAX_PACKET  (2u + LOG_MAX_PAYLOAD + 2u)

typedef char log_payload_guard[(sizeof(log_rec_t) <= LOG_MAX_PAYLOAD) ? 1 : -1];

static uint32_t g_wr = LOG_BASE;
static uint32_t g_used_bytes = 0;
static uint32_t g_seq = 0;
static uint32_t g_since_key = 0;
static uint32_t g_records_total = 0;

static uint32_t g_buf_used = 0;
static uint8_t g_buf[LOG_PAGE_MAX];

static uint8_t g_flash_ok = 0;
static uint8_t g_force_key = 1;
static uint8_t g_need_key = 1;
static uint8_t g_have_prev = 0;
static log_rec_t g_prev = {0};

static uint32_t g_drop_count = 0;
static uint32_t g_flash_fail_count = 0;

static uint16_t g_ram_wr = 0;
static uint16_t g_ram_count = 0;
static log_rec_t g_ram[LOG_RAM_RECS];

static void uart_write_len(const char* s, int n, uint32_t cap) {
  if ((s == 0) || (n <= 0) || (cap == 0u)) {
    return;
  }
  uint32_t len = (uint32_t)n;
  if (len >= cap) {
    len = cap - 1u;
  }
  for (uint32_t i = 0; i < len; ++i) {
    uart2_putc(s[i]);
  }
}

static uint16_t crc16_ccitt(const uint8_t* data, uint32_t len) {
  uint16_t crc = 0xFFFFu;
  for (uint32_t i = 0; i < len; ++i) {
    crc ^= (uint16_t)data[i] << 8;
    for (uint32_t b = 0; b < 8; ++b) {
      if (crc & 0x8000u) {
        crc = (uint16_t)((crc << 1) ^ 0x1021u);
      } else {
        crc <<= 1;
      }
    }
  }
  return crc;
}

static uint32_t zigzag_encode(int32_t v) {
  return ((uint32_t)v << 1) ^ ((uint32_t)(v >> 31));
}

static int32_t zigzag_decode(uint32_t v) {
  return (int32_t)((v >> 1) ^ (uint32_t)(-(int32_t)(v & 1u)));
}

static uint32_t put_uvar(uint8_t* dst, uint32_t cap, uint32_t v) {
  uint32_t n = 0;
  do {
    if (n >= cap) {
      return 0;
    }
    uint8_t b = (uint8_t)(v & 0x7Fu);
    v >>= 7;
    if (v != 0u) {
      b |= 0x80u;
    }
    dst[n++] = b;
  } while (v != 0u);
  return n;
}

static uint32_t put_svar(uint8_t* dst, uint32_t cap, int32_t v) {
  return put_uvar(dst, cap, zigzag_encode(v));
}

static int get_uvar(const uint8_t* src, uint32_t len, uint32_t* off, uint32_t* out) {
  uint32_t val = 0;
  uint32_t shift = 0;
  while ((*off) < len && shift < 35u) {
    uint8_t b = src[(*off)++];
    val |= ((uint32_t)(b & 0x7Fu) << shift);
    if ((b & 0x80u) == 0u) {
      *out = val;
      return 0;
    }
    shift += 7u;
  }
  return -1;
}

static int get_svar(const uint8_t* src, uint32_t len, uint32_t* off, int32_t* out) {
  uint32_t zz = 0;
  if (get_uvar(src, len, off, &zz) != 0) {
    return -1;
  }
  *out = zigzag_decode(zz);
  return 0;
}

static uint16_t clamp_u16(int32_t v) {
  if (v < 0) {
    return 0;
  }
  if (v > 65535) {
    return 65535;
  }
  return (uint16_t)v;
}

static uint16_t ram_oldest_idx(void) {
  return (uint16_t)((g_ram_wr + LOG_RAM_RECS - g_ram_count) % LOG_RAM_RECS);
}

static uint16_t ram_newest_idx(void) {
  return (uint16_t)((g_ram_wr + LOG_RAM_RECS - 1u) % LOG_RAM_RECS);
}

static int ram_peek_oldest(log_rec_t* out) {
  if ((out == 0) || (g_ram_count == 0u)) {
    return -1;
  }
  *out = g_ram[ram_oldest_idx()];
  return 0;
}

static void ram_pop_oldest(void) {
  if (g_ram_count > 0u) {
    --g_ram_count;
  }
}

static void ram_push(const log_rec_t* r) {
  if (r == 0) {
    return;
  }

  if (g_ram_count > 0u && g_ram[ram_newest_idx()].seq == r->seq) {
    return;
  }

  if (g_ram_count < LOG_RAM_RECS) {
    g_ram_count++;
  } else {
    g_drop_count++;
  }
  g_ram[g_ram_wr] = *r;
  g_ram_wr++;
  if (g_ram_wr >= LOG_RAM_RECS) {
    g_ram_wr = 0;
  }
}

static int flash_probe(void) {
  uint32_t id = 0;
  if (w25q_init() != 0) {
    return -1;
  }
  if (w25q_read_jedec_id(&id) != 0) {
    return -2;
  }
  return 0;
}

static void addr_advance(uint32_t* addr, uint32_t n) {
  uint32_t end = LOG_BASE + LOG_SIZE;
  uint32_t v = *addr + n;
  while (v >= end) {
    v -= LOG_SIZE;
  }
  *addr = v;
}

static void account_written(uint32_t n) {
  if (g_used_bytes < LOG_SIZE) {
    uint32_t room = LOG_SIZE - g_used_bytes;
    g_used_bytes += (n > room) ? room : n;
  }
}

static int flash_read_wrap(uint32_t addr, uint8_t* dst, uint32_t n) {
  uint32_t end = LOG_BASE + LOG_SIZE;
  uint32_t first = n;
  if ((addr + n) > end) {
    first = end - addr;
  }
  if (first > 0u) {
    if (w25q_read(addr, dst, first) != 0) {
      return -1;
    }
  }
  if (first < n) {
    if (w25q_read(LOG_BASE, dst + first, n - first) != 0) {
      return -2;
    }
  }
  return 0;
}

static int log_flush_chunk(const uint8_t* data, uint32_t len) {
  uint32_t off = 0;
  while (off < len) {
    uint32_t sector_off = g_wr & (LOG_SECTOR_SZ - 1u);
    if (sector_off == 0u) {
      if (w25q_erase_4k(g_wr) != 0) {
        return -1;
      }
    }

    uint32_t remain_flash = (LOG_BASE + LOG_SIZE) - g_wr;
    uint32_t remain_sector = LOG_SECTOR_SZ - sector_off;
    uint32_t chunk = len - off;
    if (chunk > remain_sector) chunk = remain_sector;
    if (chunk > remain_flash) chunk = remain_flash;

    if (w25q_write(g_wr, data + off, chunk) != 0) {
      return -2;
    }

    g_wr += chunk;
    if (g_wr >= (LOG_BASE + LOG_SIZE)) {
      g_wr = LOG_BASE;
    }
    account_written(chunk);
    off += chunk;
  }
  return 0;
}

static int flush_buffer_to_flash(void) {
  if (g_buf_used == 0u) {
    return 0;
  }
  if (!g_flash_ok) {
    return -1;
  }
  if (log_flush_chunk(g_buf, g_buf_used) != 0) {
    return -2;
  }
  g_buf_used = 0;
  g_need_key = 1;
  return 0;
}

static int encode_key_packet(const log_rec_t* r, uint8_t* out, uint32_t cap, uint32_t* out_len) {
  uint32_t payload_len = (uint32_t)sizeof(log_rec_t);
  uint32_t total = 2u + payload_len + 2u;
  if ((payload_len > 255u) || (total > cap)) {
    return -1;
  }
  out[0] = LOG_PKT_KEY;
  out[1] = (uint8_t)payload_len;
  memcpy(&out[2], r, payload_len);
  uint16_t crc = crc16_ccitt(out, 2u + payload_len);
  out[2u + payload_len] = (uint8_t)(crc & 0xFFu);
  out[3u + payload_len] = (uint8_t)(crc >> 8);
  *out_len = total;
  return 0;
}

static int encode_delta_payload(const log_rec_t* prev, const log_rec_t* cur, uint8_t* out, uint32_t cap, uint32_t* out_len) {
  uint32_t off = 0;
  uint32_t n = 0;

  if ((cur->seq < prev->seq) || (cur->ms < prev->ms)) {
    return -1;
  }

#define PUT_U(VAR) \
  do { \
    n = put_uvar(out + off, cap - off, (uint32_t)(VAR)); \
    if (n == 0u) return -1; \
    off += n; \
  } while (0)
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

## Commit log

2026-02-21 Add new component symbols and simulation scripts
    - Added USBLC6-2SC6 symbol to the KiCad library.
    - Added W25Q128JVSIQ symbol to the KiCad library.
    - Added W25Q32JVSSIQ symbol to the KiCad library.
    - Created new simulation scripts for 3D aerodynamics and flight dynamics, including:
    - aero_coefficients.m
    - aerodinamics.m
    - attitude_sim.m
    - drag_model.m
    - equations_6dof.m
    - geometry_loader.m
    - mass_properties.m
    - stability_analysis.m
    - test_aero_limits.m
    - Added atmosphere.py, constants.py, detect_apogee.py, dynamics.py, forces.py, integrators.py, monte_carlo.py, sensor_models.py, simulate.py, test_constant_drag.py, and test_no_drag.py for flight simulations.
    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
    [Boros Rocket.kicad_pcb, Boros Rocket.kicad_sch, BorosRocket.stl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]
2026-02-21 Refactor code structure for improved readability and maintainability
    [Boros Rocket.kicad_pcb, Boros Rocket.kicad_sch]
2026-02-21 Add firmware support for BMP390 and ICM42688 sensors
    - Implemented BMP390 driver for pressure and temperature readings.
    - Added ICM42688 driver for accelerometer and gyroscope data acquisition.
    - Introduced SPI communication functions for sensor interaction.
    - Created GPIO management functions for chip select and buzzer control.
    - Developed logging functionality to record sensor data and system status.
    - Set up UART for communication and debugging output.
    - Configured system initialization and SysTick for timing.
    - Added linker script and startup assembly for STM32G071 microcontroller.
    - Implemented main application logic to initialize sensors and process data.
    [bmp390.c, flash_w25q.c, gpio.c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]
2026-02-21 feat: Implement flight simulation and logging features
    - Added sensor models for generating firmware-like logs in `sensor_models.py`.
    - Developed a simulation script in `simulate.py` to run flight simulations and output results.
    - Created tests for constant drag and no drag scenarios in `test_constant_drag.py` and `test_no_drag.py`.
    - Introduced CI workflow in `.github/workflows/ci.yml` for automated testing and firmware builds.
    - Added Makefile for build automation and simplified command execution.
    - Implemented MATLAB/Octave 3D simulation runner in `run_ci_sim.m`.
    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
2026-02-21 Add logging functionality, SPI communication, and telemetry dump tool
    - Created log.h for logging flags and log record structure.
    - Implemented SPI communication in spi.c for SPI1 initialization and data transfer.
    - Developed a Python script (dump.py) for capturing telemetry data over UART with automatic port detection and CSV output.
    - Added requirements.txt to specify the pyserial dependency for the telemetry dump tool.
2026-02-21 fix: Correct ARM GCC path in CI workflow
2026-02-21 fix: Update RecoveryConfig parameters for optimal rocket performance and enhance JSON loading functions in CI report
    [ci_report.py]
2026-02-21 Add Gerber job file for Boros Rocket PCB design
    - Created a new Gerber job file 'Boros Rocket-job.gbrjob' for the Boros Rocket project.
    - Included project specifications such as size, layer number, and board thickness.
    - Defined design rules for outer and inner layers.
    - Specified file attributes for copper layers, solder masks, silkscreens, and assembly drawings.
    - Documented material stackup including thickness and type for each layer.
    [Boros Rocket-B_Cu.gbr, Boros Rocket-B_Mask.gbr, Boros Rocket-B_Paste.gbr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]
2026-02-21 fix: Remove obsolete NPTH drill and Gerber files from the PCB directory
    [Boros Rocket-NPTH-drl.gbr, Boros Rocket-NPTH.drl]
2026-02-21 Refactor code structure for improved readability and maintainability
    Remaking Rocket again(3D)
    [Boros Rocket - Plate.kicad_pcb, BorosRocket.stl, BorosToPrint.stl]
2026-02-21 Add mass budget computation tool for STL, motor, and PCB plate
    - Implemented a new script `mass_budget.py` to calculate the mass budget based on STL geometry, motor specifications, and PCB plate details.
    - The script includes functionality to generate both JSON and Markdown outputs summarizing the mass budget.
    - Added command-line arguments for user input, including STL path, motor mass, airframe density, and PCB specifications.
    - Integrated functions to convert units and calculate various mass components, including airframe, PCB, and total estimated liftoff mass.
    [Boros Rocket - Plate-B_Cu.gbr, Boros Rocket - Plate-B_Mask.gbr, Boros Rocket - Plate-B_Paste.gbr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]
2026-02-21 Refactor code structure for improved readability and maintainability
    Implemented V4 PCB!
    [Boros Rocket .kicad_pcb, Boros Rocket.kicad_pcb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]
2026-03-07 Fixed 3D
    [BorosRocket_ToPrint.stl]
2026-03-21 Add new components to bom_mouser.csv
    Added new components to the BOM from Mouser, including various capacitors, resistors, sensors, and microcontrollers.
    [bom_mouser.csv]
2026-03-21 Revise bom_mouser.csv with headers and descriptions
    Updated the BOM file format to include headers and improved component descriptions.
    [bom_mouser.csv]
2026-03-21 Create bom_total.csv with component details
    Added a bill of materials (BOM) with components, pricing, and notes.
    [bom_total.csv]
